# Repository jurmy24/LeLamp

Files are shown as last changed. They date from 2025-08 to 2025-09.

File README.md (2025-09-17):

# LeLamp

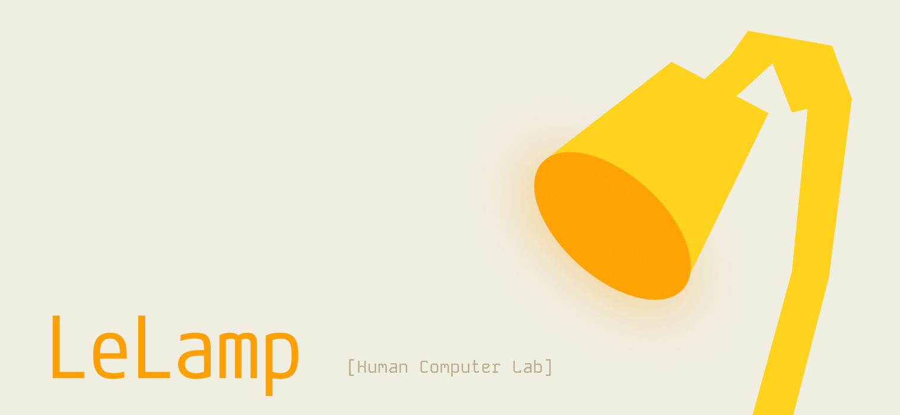
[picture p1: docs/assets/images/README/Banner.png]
LeLamp Banner


An open source robot lamp based on [Apple's Elegnt](https://machinelearning.apple.com/research/elegnt-expressive-functional-movement), made by [Human Computer Lab](https://www.humancomputerlab.com/)

## Overview

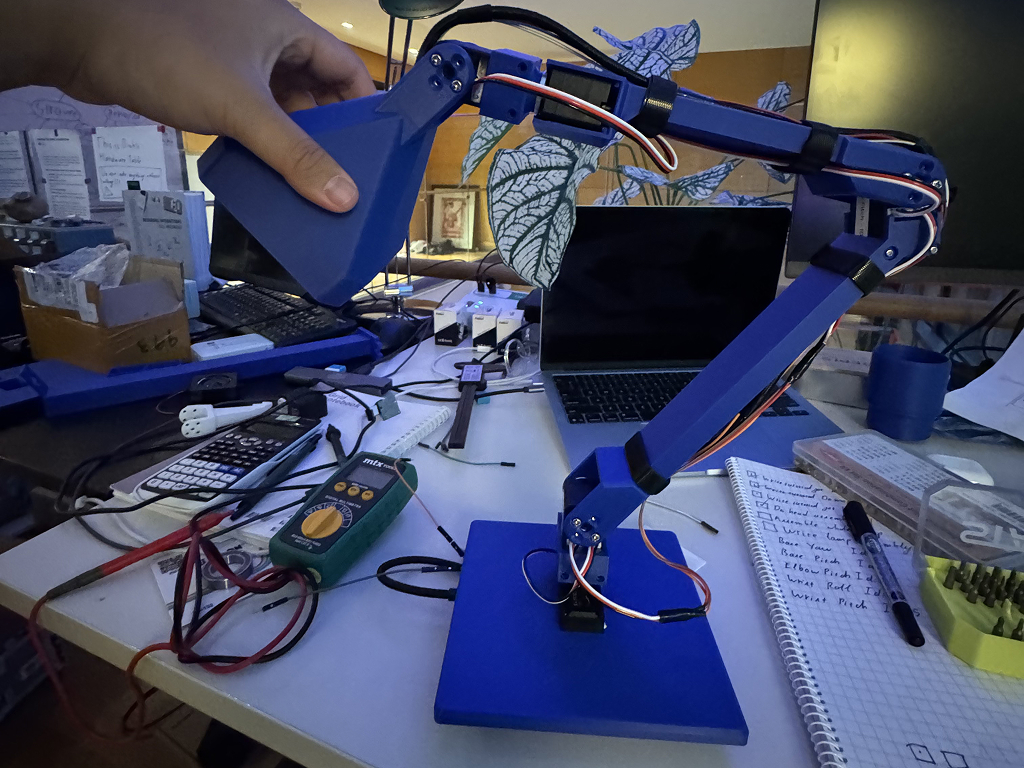
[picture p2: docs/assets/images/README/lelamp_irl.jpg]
LeLamp in real life


**Build specs:** ~$130 cost | 8-12 hours | Intermediate skill level

LeLamp is an expressive robot lamp featuring:

- 🎭 **5-axis articulated movement** with servo motors
- 📸 **Computer vision** via Pi Camera
- 🎤 **Audio interaction** with microphone and speaker
- 💡 **LED expressions** with 24 programmable LEDs
- 🎮 **Record & replay** custom movements

## Build Guide

**Start here:** [Prerequisites & Planning](./docs/0.%20Prerequisites.md)

### Complete Build Process

1. [📋 Prerequisites & Planning](./docs/0.%20Prerequisites.md) - Skills, tools, and BOM
2. [🔧 Components & 3D Parts](./docs/1.%20Schematics.md) - Technical specs and electrical layout
3. [⚙️ Servo Setup](./docs/2.%20Servos.md) - Configure servo motors
4. [🎯 Lamp Head Assembly](./docs/3.%20Lamp%20Head.md) - Pi, camera, audio, LEDs
5. [🏗️ Lamp Body Assembly](./docs/4.%20Lamp%20Body.md) - Mechanical assembly
6. [🎮 Lamp Control](./docs/5.%20Lamp%20Control.md) - Recording and playback
7. [🔍 Troubleshooting](./docs/6.%20Troubleshooting.md) - Common issues and solutions

### Quick Reference

- **Bill of Materials**: [Complete component list with suppliers](./docs/0.%20Prerequisites.md#bill-of-materials)
- **3D Print Files**: Available in `/3D/` directory ([OnShape CAD](https://cad.onshape.com/documents/16c9706360b5ad34f9c8db49/w/2edfa54c83253c120fbc9e58/e/a7196194821d9cfe2842a44a))
- **Software Control**: [LeLamp Runtime Repository](https://github.com/humancomputerlab/lelamp_runtime)

## Project Status

⚠️ **Early Development** - This project is actively being developed. We published our progress early to encourage community feedback and iteration.

## Community & Support

### Getting Help

- **Start here**: [Troubleshooting Guide](./docs/6.%20Troubleshooting.md) for common issues
- **Discord**: [Join our community](https://discord.gg/727JXBt8Zt) for real-time help and discussions
- **GitHub Issues**: [Report bugs or ask questions](https://github.com/humancomputerlab/le_lamp/issues)

### Contributing

We welcome contributions:

- 🐛 Bug reports and fixes
- 📖 Documentation improvements
- 🔧 Design enhancements
- 🌍 Regional supplier information
- 📸 Build photos and videos

Please check existing issues before creating new ones.

## Sponsor

Biggest thanks to Jennie and Lily at Seeed Studio for sponsoring the SO-101 Arm Kit for early developments of LeLamp.

Buy an SO-101 Arm Kit today on [SeeedStudio](https://www.seeedstudio.com/SO-ARM101-Low-Cost-AI-Arm-Kit-p-6426.html).

## License

This project is licensed under the GNU General Public License v3.0 - see the [LICENSE](LICENSE) file for details.

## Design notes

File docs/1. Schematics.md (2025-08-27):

# Building your own LeLamp



The schematic above is for the Pi Zero variation of LeLamp. Scroll down for the normal Pi variation.

## Technical Specifications

### Power Requirements

- **Operating voltage**: 5V DC
- **Total power consumption**: <15W (3A peak)
- **Servo power**: 5V @ 2.5A (all 5 servos under load)
- **Pi and peripherals**: 5V @ 0.5A

LeLamp's servos can also be powered with a 7.4V power supply.

### Performance Specifications

- **Servo torque**: 19kg-cm per servo (STS3215)
- **Position accuracy**: ±2° servo resolution
- **Movement speed**: Up to 60°/second per joint
- **Camera resolution**: 1296x972 @ 30fps
- **Audio**: 16kHz sampling, 2-channel input, mono output
- **LED ring**: 24x WS2812B programmable LEDs

### 3D Printing Requirements

- **Material**: PLA+ recommended (PETG acceptable)
- **Layer height**: 0.2mm standard, 0.15mm for critical parts
- **Infill**: 20% minimum, 30% for structural components
- **Print volume**: 200x200x150mm minimum printer bed

## Electrical Components

**Complete Bill of Materials**: See [Prerequisites Documentation](./0.%20Prerequisites.md#bill-of-materials) for detailed component list with supplier links.

LeLamp is divided into two main sections:

- **Lamp Body** – Houses the mechanical actuation and power conversion systems. This includes:

  - High-torque servos for movement
  - A servo driver board for precise positioning
  - A DC-DC buck converter to regulate 7.4V V down to 5 V for low-voltage electronics

  Think of the Lamp Body like the human torso—it contains the “muscles” (servos) and “circulatory system” (power delivery) that keep the whole device moving.

- **Lamp Head** – Contains the computing and expressive modules, including:

  - Raspberry Pi Zero 2W for control and connectivity
  - Camera module for vision
  - WS2812B RGB LED ring for expressive lighting
  - Microphone and speaker system for audio interaction

  The Lamp Head is like a human head—it houses the “brain” (Pi), the “eyes” (camera), the “ears” (microphone), and the “mouth” (speaker and LEDs).

You can build a functional LeLamp without most of the head components—or even without the head entirely—if you prefer to control the servos directly from an external computer.

## 3D Prints

### With Pi Zero

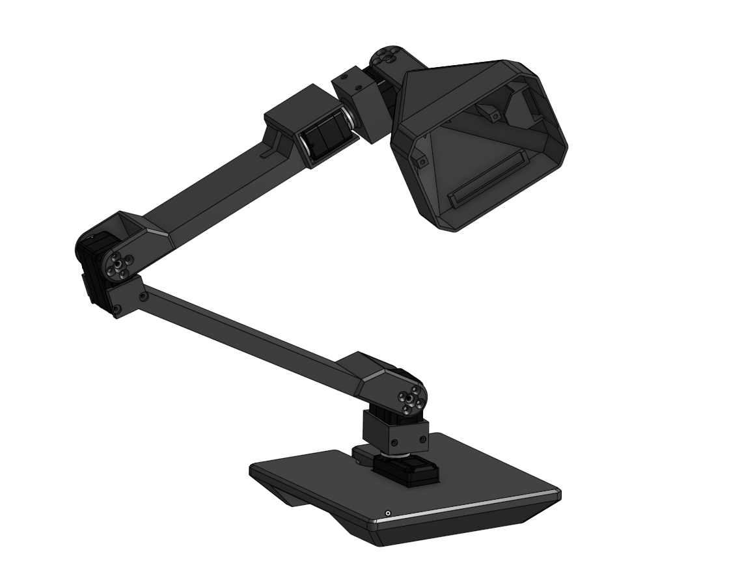
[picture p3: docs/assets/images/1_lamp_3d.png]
3D Lamp


In this variation, LeLamp contains 7 3D printed components:

- **1x Lamp Base**: Contains servo driver, speaker and base yaw servo.
- **1x LampArm (Base to Elbow)**: Contains base pitch and elbow pitch servo.
- **1x LampArm (Elbow to Wrist)**: Contains elbow pitch and wrist roll servo.
- **2x LampArm (Wrist to Head)**: Contains base pitch or wrist pitch servo.
- **1x Lamp Head**: Contains pi zero, led matrix and camera.

You can find the .3mf files for these inside `/3D/`. You can also view it in [OnShape](https://cad.onshape.com/documents/16c9706360b5ad34f9c8db49/w/2edfa54c83253c120fbc9e58/e/a7196194821d9cfe2842a44a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).

### With Normal Pi

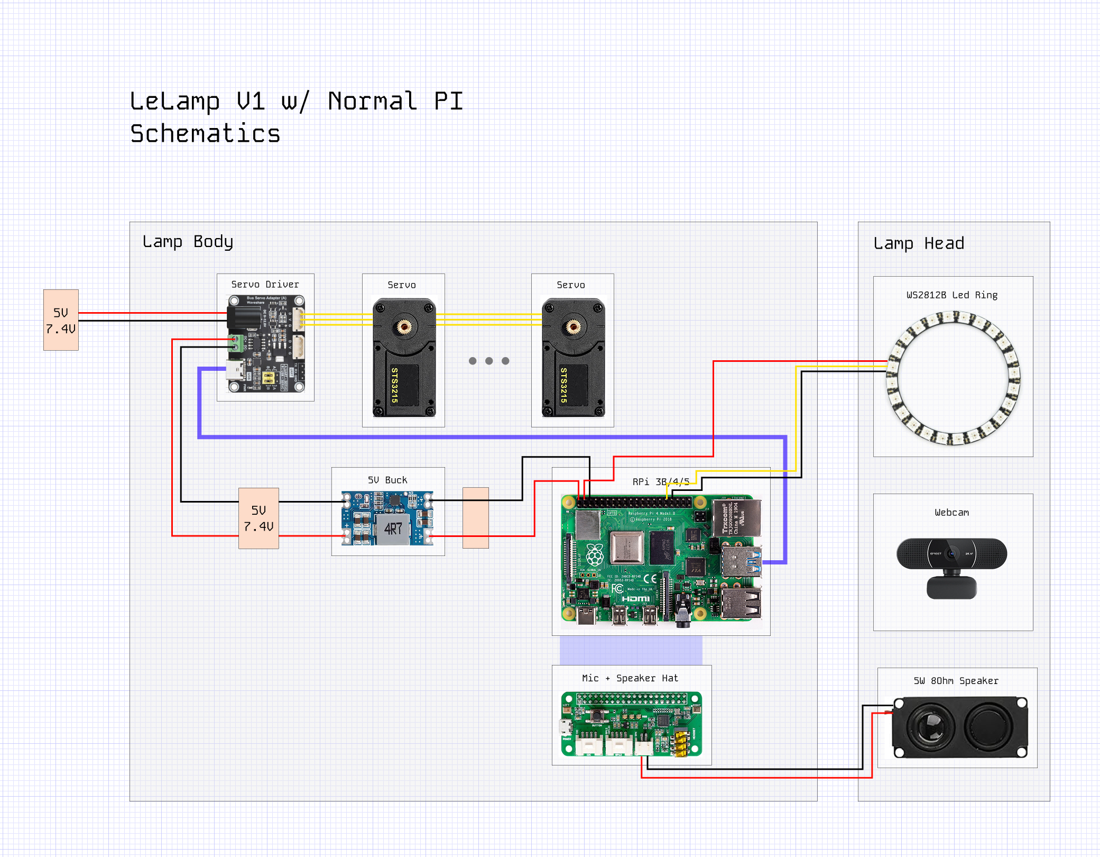
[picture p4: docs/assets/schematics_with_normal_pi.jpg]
Schematic with normal Pi


In this variation, LeLamp contains 7 3D printed components:

- **1x Lamp Base**: Contains servo driver and a normal pi.
- **1x Lamp Base Cover**: Cover lamp base.
- **1x LampArm (Base to Elbow)**: Contains base pitch and elbow pitch servo.
- **1x LampArm (Elbow to Wrist)**: Contains elbow pitch and wrist roll servo.
- **2x LampArm (Wrist to Head)**: Contains base pitch or wrist pitch servo.
- **1x Lamp Head**: Contains led matrix and speaker.

You can find the .3mf files for these inside `/3D/`. The specific files for this version can be found in `/3D/normal_pi_variation/`.

The tutorial will not focus on this version. However, the connection can be referenced from the schematics. The motor orientation and software set up stay the same.

**Previous**: [Prerequisites](./0.%20Prerequisites.md) | **Next**: [Servo Setup](./2.%20Servos.md)

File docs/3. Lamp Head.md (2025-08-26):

# Lamp Head Assembly

**⏱️ Estimated time:** 3-4 hours (including OS setup)  
**🔧 Required tools:** Soldering iron, screwdrivers, heat insert tool  
**📦 Required components:** Pi Zero 2W, ReSpeaker Hat, camera, speaker, LED ring, SD card



LeLamp's head has 4 main functional components:

- **Microphone** - Audio input via ReSpeaker Hat
- **Speaker** - Audio output (4Ω 3W)
- **LED Ring** - 24x WS2812B programmable LEDs for expression
- **Camera** - Pi camera module for vision

All of these components are connected and controlled by a Pi Zero 2W.

## Assembly

Before mounting all components onto the lamp head, it is advised to assemble the electrical components first and test them. You can reference the above image for how this looks like.

### 1. OS

Using [Pi Imager](https://www.raspberrypi.com/software/), flash **Raspberry Pi OS Lite (64-bit)** onto your Raspberry Pi Zero 2W. You can reference how to do this [here](https://www.raspberrypi.com/documentation/computers/getting-started.html). In this tutorial, we used the Debian Bookworm version (released 2025-05-13).

When prompted to configure the settings on your pi, remember to:

- Set the Wifi SSID and password.
- Set the username and password.
- Set the hostname
- Enable SSH

### 2. Runtime

After successfully flashing your pi, SSH into it by running the following command:

```bash
ssh your_username@your_host_name.local
```

Then you need to set up [LeLamp Runtime](https://github.com/humancomputerlab/lelamp_runtime):

```bash
git clone https://github.com/humancomputerlab/lelamp_runtime.git
```

To use LeLamp's runtime, install uv:

```bash
curl -LsSf https://astral.sh/uv/install.sh | sh
```

To setup the runtime:

```bash
cd lelamp_runtime
uv sync --extra hardware
```

This will take a while.

### 3. Setup Mic and Speaker

If you use the ReSpeaker Hat for Raspberry Pi, you can reference their tutorial [here](https://wiki.seeedstudio.com/respeaker_2_mics_pi_hat_raspberry_v2/). For convenience, the tutorial is below:

1. Get Device Tree Source (DTS) for the ReSpeaker 2-Mics Pi HAT (V2.0), compile it and install the device tree overlay.

   ```bash
   curl https://raw.githubusercontent.com/Seeed-Studio/seeed-linux-dtoverlays/refs/heads/master/overlays/rpi/respeaker-2mic-v2_0-overlay.dts -o respeaker-2mic-v2_0-overlay.dts
   dtc -I dts respeaker-2mic-v2_0-overlay.dts -o respeaker-2mic-v2_0-overlay.dtbo
   sudo dtoverlay respeaker-2mic-v2_0-overlay.dtbo
   sudo cp respeaker-2mic-v2_0-overlay.dtbo /boot/firmware/overlays
   ```

2. Edit /boot/firmware/config.txt:

   ```bash
   sudo tee -a /boot/firmware/config.txt >/dev/null <<'EOF'
   dtoverlay=respeaker-2mic-v2_0-overlay
   dtoverlay=i2s-mmap
   EOF
   ```

3. Reboot your device:

   ```bash
   sudo reboot
   ```

4. Check if your device is enabled:

   ```bash
   aplay -l
   ```

   The expected output should be like this:

   ```bash
   card 2: seeed2micvoicec [seeed2micvoicec], device 0: 1f000a4000.i2s-tlv320aic3x-hifi tlv320aic3x-hifi-0 [1f000a4000.i2s-tlv320aic3x-hifi tlv320aic3x-hifi-0]
   Subdevices: 1/1
   Subdevice #0: subdevice #0
   ```

   Afterwards, you can set up the sound level with the following command:

   ```bash
   alsamixer
   ```

5. Install the necessary dependencies for audio:

   ```bash
   sudo apt-get install portaudio19-dev
   ```

### 4. Test functionalities

#### Camera

For camera, run the following command:

```bash
libcamera-hello
```

You should expect an output like this:

```bash
[0:07:48.563548988] [1773]  INFO Camera camera_manager.cpp:326 libcamera v0.5.0+59-d83ff0a4
[0:07:48.749650563] [1777]  WARN RPiSdn sdn.cpp:40 Using legacy SDN tuning - please consider moving SDN inside rpi.denoise
[0:07:48.755845206] [1777]  INFO RPI vc4.cpp:447 Registered camera /base/soc/i2c0mux/i2c@1/ov5647@36 to Unicam device /dev/media2 and ISP device /dev/media0
[0:07:48.756141873] [1777]  INFO RPI pipeline_base.cpp:1121 Using configuration file '/usr/share/libcamera/pipeline/rpi/vc4/rpi_apps.yaml'
Preview window unavailable
Mode selection for 1296:972:12:P
    SGBRG10_CSI2P,640x480/0 - Score: 3296
    SGBRG10_CSI2P,1296x972/0 - Score: 1000
    SGBRG10_CSI2P,1920x1080/0 - Score: 1349.67
    SGBRG10_CSI2P,2592x1944/0 - Score: 1567
Stream configuration adjusted
[0:07:48.781597581] [1773]  INFO Camera camera.cpp:1205 configuring streams: (0) 1296x972-YUV420 (1) 1296x972-SGBRG10_CSI2P
[0:07:48.782340394] [1777]  INFO RPI vc4.cpp:622 Sensor: /base/soc/i2c0mux/i2c@1/ov5647@36 - Selected sensor format: 1296x972-SGBRG10_1X10 - Selected unicam format: 1296x972-pGAA
#0 (0.00 fps) exp 33239.00 ag 8.00 dg 1.00
#1 (30.00 fps) exp 33239.00 ag 8.00 dg 1.00
#2 (30.01 fps) exp 33239.00 ag 8.00 dg 1.00
```

#### RGB

For RGB, run the following command with sudo:

```bash
sudo uv run -m lelamp.test.test_rgb
```

In case you can't find uv as root, run:

```bash
which uv
```

Then replace uv with the output, for example:

```bash
sudo /home/pi/.local/bin/uv run -m lelamp.test.test_rgb
```

If you don't want to do this long path every single time, you can add the path to uv to sudo's secure path:

```bash
sudo visudo
```

Add the following `/home/pi/.local/bin` (Remember to change your username):

```bash
Defaults secure_path="/usr/local/sbin:/usr/local/bin:/usr/sbin:/usr/bin:/sbin:/bin:/home/pi/.local/bin"
```

#### Mic and Speaker

For Mic and Speaker, run the following command:

```bash
uv run -m lelamp.test.test_audio
```

#### Servo

Connect Pi Zero 2W to the servo driver through the USB port, then run the following to find which port the servo is connected to:

```bash
uv run lerobot-find-port
```

Then run the following command to check whether the servos are available:

```bash
uv run -m lelamp.test.test_motors --id your_lamp_name --port port_your_servo_driver_is_connected_to
```

Note: There is an error in LeRobot that makes it impossible to be used on Raspberry Pi. Check the status of this error [here](https://github.com/huggingface/lerobot/issues/1738).

### 5. Assembly

For reference, this will be what the lamp head will look like. Please reference the schematics in **1. Schematics** while doing this step.

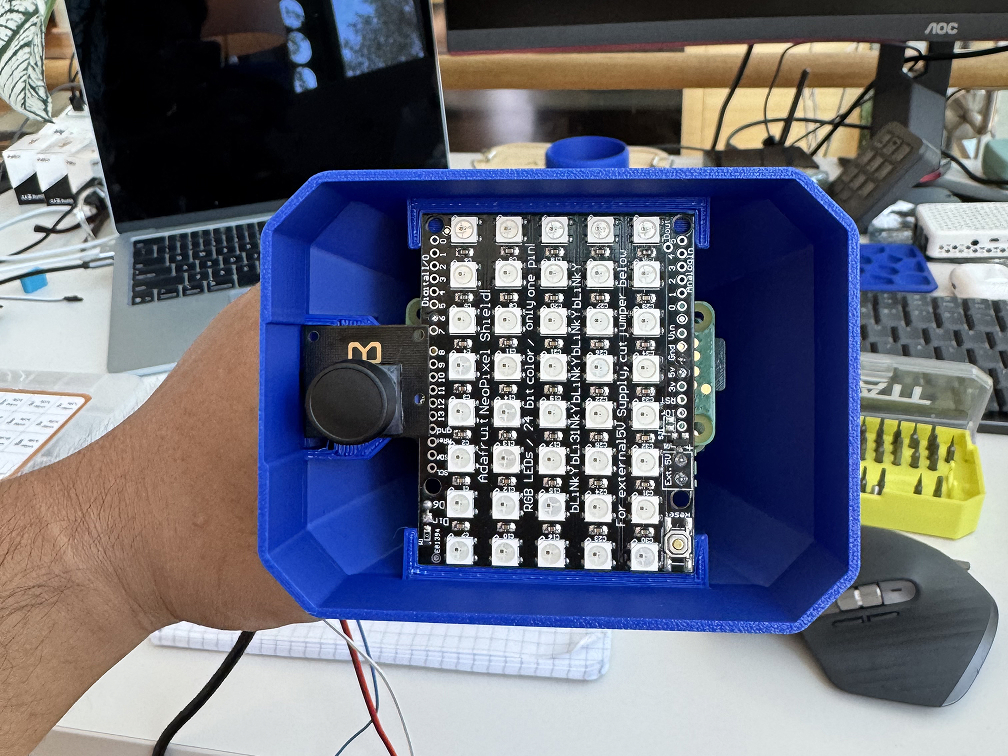
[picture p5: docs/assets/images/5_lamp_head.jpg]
Lamp Head


#### ReSpeaker Hat

Prior to mounting, it is recommended to solder headers on the the ReSpeaker Hat. This will help you connect to components as shown in the schematics.

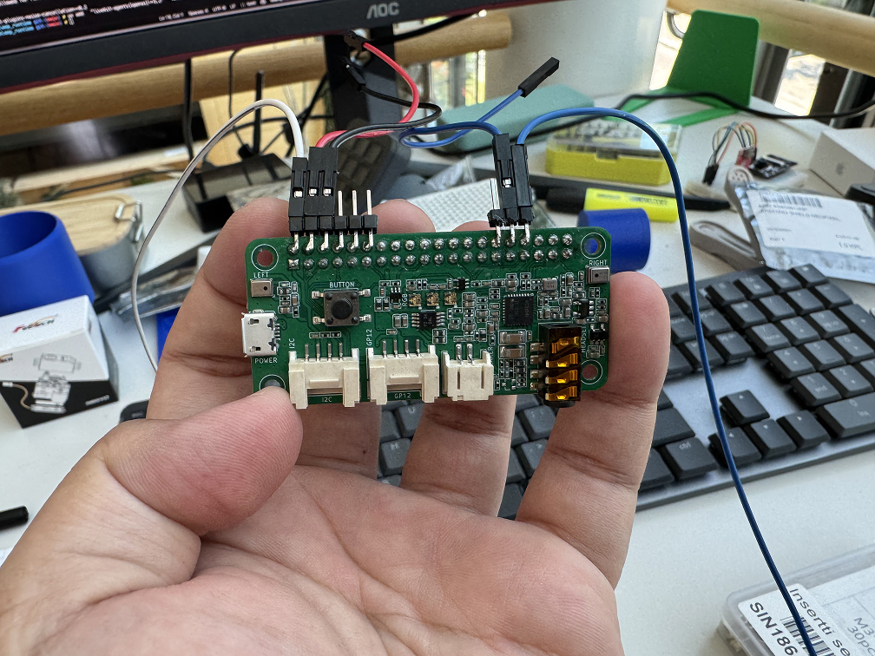
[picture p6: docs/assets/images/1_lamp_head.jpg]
ReSpeaker Hat


Then you should put M2 heat inserts into the mounting pads for the ReSpeaker Hat in the lamp head.

Before screwing the hat in, you should route the wires into the hat first. This includes speaker wire, power wire and rgb wire. It should look like this after mounting.

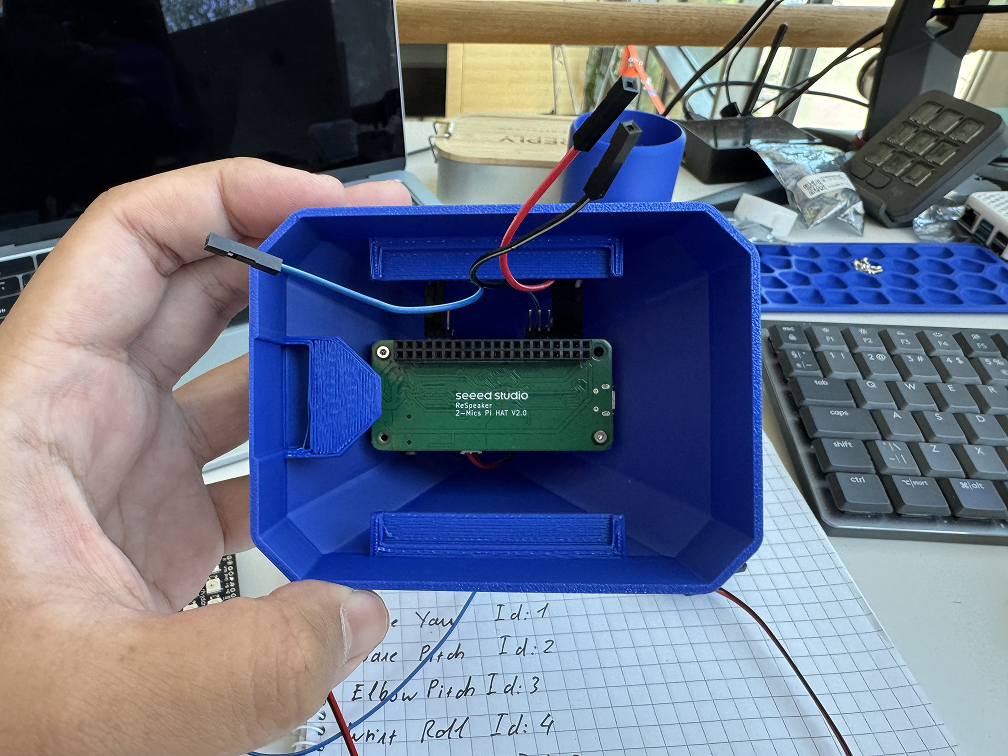
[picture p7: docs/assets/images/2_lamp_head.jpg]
Lamp Head


**At this stage, you should plug in the speaker into the JST2.0 input. Unlike the schematics, you should route this outside the lamp head. This is a temporary design compromise for now, since the speaker is too big.**

#### Raspberry Pi Zero 2W

Slide your Micro USB to Type C wire into the lamp head first, then connect it to the Raspberry Pi Zero 2W.

It should look like this:

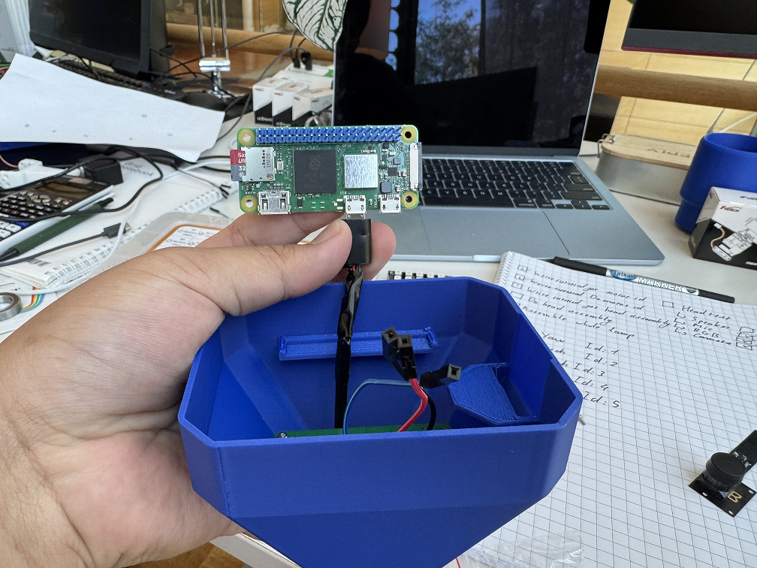
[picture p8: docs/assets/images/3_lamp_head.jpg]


#### RGB Shield And Camera



You should connect the camera by sliding the camera wire into the camera slit first, then connect to the pi.

You can connect the pi to the RGB shield. This should be easy if you have soldered the headers onto the speaker hat before.

## Assembly Completion Checklist

After completing lamp head assembly, verify:

- [ ] Pi Zero 2W boots successfully and connects to WiFi
- [ ] Camera detected and produces clear images (`libcamera-hello`)
- [ ] Audio input/output working (microphone and speaker)
- [ ] LED ring lights up and cycles through colors
- [ ] All connections secure and properly routed
- [ ] LeLamp runtime installed and dependencies working
- [ ] All component tests pass successfully

## What You Should Have

At this stage, you should have:

- **Functional head assembly** with all electronics working
- **Working Pi setup** with SSH access and runtime installed
- **Tested components** - camera, audio, LEDs all operational
- **Proper cable management** with wires routed through head structure

---

**Previous**: [Servo Setup](./2.%20Servos.md) | **Next**: [Lamp Body](./4.%20Lamp%20Body.md)

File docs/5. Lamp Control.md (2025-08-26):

# Lamp Control

**⏱️ Estimated time:** 30 minutes  
**🔧 Required tools:** Computer with LeLamp runtime  
**📦 Required:** Fully assembled LeLamp with working head and body

For complete lamp control documentation, refer to the [**LeLamp Runtime's GitHub**](https://github.com/humancomputerlab/lelamp_runtime).

If you have run tests for LeLamp Head earlier, you should be familiar with the runtime.

## Calibration

Before recording and replaying movements on the lamp, you need to calibrate:

```bash
uv run -m lelamp.calibrate --id lelamp --port /dev/tty.usbmodem5A680114681
```

The calibration script will run calibration twice, once for the lamp as a follower and once for the lamp as the leader.

**Note: Do not rotate the lamp base and lamp head fully while calibrating. This means the 2 yaw servos. In zero position, rotate them 90 degrees clockwise and counter clockwise.**

## Record and replay movements

To record movement, run the following command in runtime:

```bash
uv run -m lelamp.record --id lelamp --port /dev/tty.usbmodem5A680114681 --name rotation
```

To replay movement, run the following command in runtime:

```bash
uv run -m lelamp.replay --id lelamp --port /dev/tty.usbmodem5A680114681 --name rotation
```

To list all recorded movements, run the following command in runtime:

```bash
uv run -m lelamp.list_recordings --id lelamp
```

## Final System Testing

After completing your LeLamp build, perform these final tests:

### Full System Integration Test

```bash
# Test all servo movements
uv run -m lelamp.test.test_motors --id lelamp --port /dev/ttyUSB0

# Test head components
sudo uv run -m lelamp.test.test_rgb     # LED ring
uv run -m lelamp.test.test_audio        # Audio I/O
libcamera-hello --timeout 2000         # Camera
```

### Record Your First Movement

1. **Position LeLamp** in a safe working area with full range of motion
2. **Record a simple movement** to test the system
3. **Replay the movement** to verify accuracy
4. **Save successful recordings** for future use

## Congratulations! 🎉

You have successfully built your LeLamp! Your robot lamp should now be capable of:

- ✅ Expressive movement through 5 degrees of freedom
- ✅ Visual interaction via camera
- ✅ Audio input/output for voice interaction
- ✅ Programmable LED expressions
- ✅ Recording and replaying custom movements

## Next Steps

- **Explore the runtime**: Check out advanced features in the [LeLamp Runtime repository](https://github.com/humancomputerlab/lelamp_runtime)
- **Join the community**: Share your build on [Discord](https://discord.gg/4hmNW3Ep)
- **Contribute back**: Help improve documentation or share build photos
- **Report issues**: Use [GitHub Issues](https://github.com/humancomputerlab/le_lamp/issues) for bugs or suggestions

---

**Previous**: [Lamp Body](./4.%20Lamp%20Body.md) | **Troubleshooting**: [Common Issues](./6.%20Troubleshooting.md)

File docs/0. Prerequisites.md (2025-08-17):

# Prerequisites for Building LeLamp

Before starting your LeLamp build, ensure you have the necessary skills, tools, and time to complete this project successfully.

## Skill Level Requirements

**Intermediate to Advanced** - This project requires:
- **Electronics experience**: Soldering, basic circuit understanding, component identification
- **3D printing knowledge**: Printer operation, material selection, post-processing
- **Software comfort**: Command line usage, SSH, basic Linux administration
- **Mechanical assembly**: Precision work with small components, heat inserts, servo mounting

**Estimated build time**: 8-12 hours over 2-3 days

## Required Tools

### Electronics Tools
- Soldering iron (temperature controlled, 15-25W)
- Solder (60/40 rosin core, 0.6-0.8mm)
- Wire strippers
- Small screwdrivers (Phillips #0, #1, flathead 2-3mm)
- Multimeter for continuity testing
- Anti-static wrist strap (recommended)

### Mechanical Tools  
- Heat insert soldering iron tip OR dedicated heat insert tool
- M2 and M3 Allen keys/hex drivers
- Small pliers (needle nose)
- Wire cutters/flush cutters
- Digital calipers (for verification)

### 3D Printing Requirements
- **Printer bed size**: Minimum 200x200x150mm
- **Materials**: PLA+ recommended (PETG acceptable)
- **Layer height**: 0.2mm standard, 0.15mm for critical parts
- **Infill**: 20% minimum, 30% for structural components
- **Supports**: Required for some parts (see individual STL notes)

## Safety Warnings

⚠️ **ELECTRICAL SAFETY**
- Always disconnect power when making connections
- Use proper ESD precautions when handling Pi and servo driver
- Main power supply is 5V - verify correct voltage before connection
- Double-check polarity before powering on

⚠️ **MECHANICAL SAFETY**
- Heat inserts reach 200°C+ - use appropriate tools
- Servo horns under tension can snap - wear eye protection
- Small parts present choking hazard

## Bill of Materials

### Lamp Body Components
| Component | Quantity | Unit Price | Total | Supplier Link |
|---|---|---|---|---|
| Feetech ST3215 Motor | 5 | $12.00 | $60.00 | [Alibaba](https://www.alibaba.com/product-detail/STS3215-7-4V-19Kg-TTL-Serial_1600114878646.html) |
| Servo Driver | 1 | $4.99 | $4.99 | [Alibaba](https://www.alibaba.com/pla/Serial-Bus-Servo-Driver-Board-Integrates_1600997533603.html) |
| Fixed Output 5V Buck Converter | 1 | $0.75 | $0.75 | [Alibaba](https://www.alibaba.com/product-detail/DC-DC-Buck-3A-Step-down_62035392561.html) |

### Lamp Head Components
| Component | Quantity | Unit Price | Total | Supplier Link |
|---|---|---|---|---|
| Pi Zero 2W | 1 | $15.85 | $15.85 | [Alibaba](https://www.alibaba.com/product-detail/Raspberry-Pi-Zero-2-Development-Board_1600886165825.html) |
| ReSpeaker Hat | 1 | $4.34 | $4.34 | [Alibaba](https://www.alibaba.com/product-detail/Ai-Voice-Applications-Shield-ReSpeaker-2_1601210422054.html) |
| Camera | 1 | $5.00 | $5.00 | [Alibaba](https://www.alibaba.com/product-detail/Aismartlink-Raspberry-Pi-Zero-2W-camera_1601380916187.html) |
| Speaker | 1 | $1.00 | $1.00 | [Alibaba](https://www.alibaba.com/product-detail/100-45mm-8ohm-4watt-High-Sound_1600873138077.html) |
| 24 LEDs WS2812B LED Ring | 1 | $6.20 | $6.20 | [Alibaba](https://www.alibaba.com/product-detail/WS2812B-Module-Strip-24-Bits-24_1600371300450.html) |

### Power & Miscellaneous
| Component | Quantity | Unit Price | Total | Supplier Link |
|---|---|---|---|---|
| 5V 2A DC Power Supply | 1 | $2.00 | $2.00 | [Alibaba](https://www.alibaba.com/product-detail/US-EU-Plug-5V-9V-12V_1600555086691.html) |
| 3D Prints | 1 set | $30.00 | $30.00 | Local printing service |
| Type C to MicroUSB Cable | 1 | $0.50 | $0.50 | [Alibaba](https://www.alibaba.com/product-detail/180-Degree-U-Shape-USB-Type_62447998101.html) |
| 16mm M3 Screws | 4 | - | - | Local hardware store |
| 4mm M2 Screws | 4 | - | - | Local hardware store |
| M2 Heat Inserts | 4 | - | - | Local hardware store |
| M3 Heat Inserts | 8 | - | - | Local hardware store |

**Total estimated cost: $130.63 USD**

## Required External Resources

Before starting, ensure you have access to:
- **3D Printer** or printing service
- **Computer** for Pi setup and servo configuration  
- **WiFi network** for Pi connectivity
- **LeLamp Runtime Repository**: https://github.com/humancomputerlab/lelamp_runtime

## Time Planning

### Phase 1: Preparation (2-3 hours)
- Download and review all documentation
- Source all components
- 3D print all parts
- Set up software environment

### Phase 2: Electronics Prep (2-3 hours)
- Test all components individually
- Solder headers and connectors
- Set up Raspberry Pi OS
- Configure servo IDs

### Phase 3: Assembly (4-6 hours)
- Install heat inserts
- Mount servos in 3D printed parts
- Route wiring through body
- Assemble head components
- Final integration and testing

## Pre-Build Checklist

- [ ] All components sourced and verified working
- [ ] 3D parts printed and post-processed
- [ ] Tools and workspace prepared
- [ ] Software downloaded and accounts created
- [ ] Safety equipment ready
- [ ] Adequate time allocated (don't rush!)

## Getting Help

If you encounter issues:
- **Discord Community**: https://discord.gg/4hmNW3Ep
- **GitHub Issues**: Report bugs and ask questions
- **Documentation**: Always check troubleshooting section first

---

**Next Step**: [1. Building your own LeLamp](./1.%20Schematics.md)

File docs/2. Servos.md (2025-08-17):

# Servo Setup

**⏱️ Estimated time:** 30-45 minutes  
**🔧 Required tools:** Computer, servo driver, USB cable  
**📦 Required components:** 5x STS3215 servos, servo driver board

The first part of building your LeLamp is setting up your servos.

## 1. Unbox and lay your servos on a table.

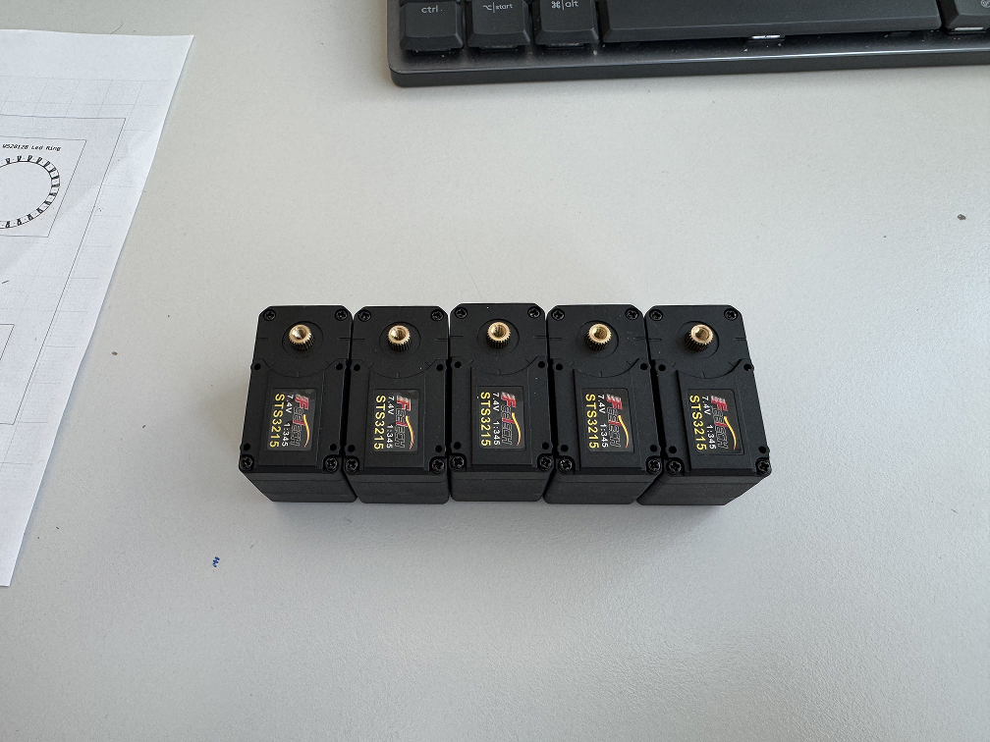
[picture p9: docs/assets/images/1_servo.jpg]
Servos on table


## 2. Label your servos.

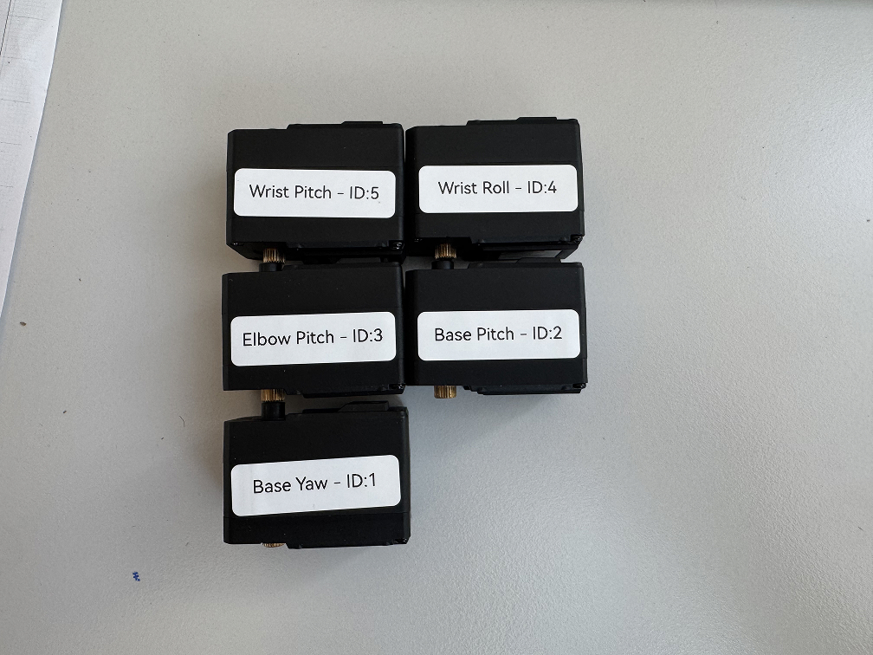
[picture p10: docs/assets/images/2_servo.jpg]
Label your servos.


| Servo Name  | Servo ID |
| --- | --- |
| base_yaw | 1 |
| base_pitch  | 2 |
| elbow_pitch | 3 |
| wrist_roll  | 4 |
| wrist_pitch | 5 |

Based on the table above, you should label your servo accordingly. There's no particular order to this or specific servo you should label with a certain ID.

The end result is having 5 servos, each with a label that tells you which is which.

## 3. Run LeLamp's motor setup script.

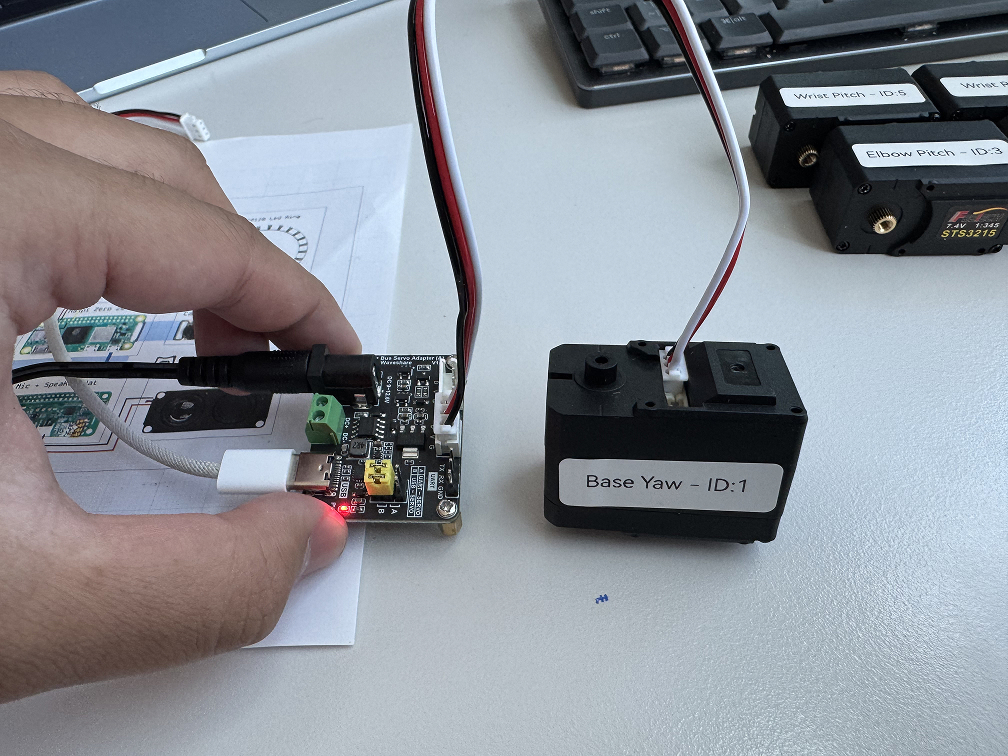
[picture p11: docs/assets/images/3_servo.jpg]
Run LeLamp's motor setup script


After labeling your servo, connect the servo driver to your computer and figure which port it is connected to.

Inside `lelamp_runtime`, you can find port this by running:

```bash
uv run lerobot-find-port
```

For motor setup, inside `lelamp_runtime`, run the following command and connect the servo accordingly:

```bash
uv run -m lelamp.setup_motors --id your_lamp_name --port port_your_servo_driver_is_connected_to
```

Example:

```bash
uv run -m lelamp.setup_motors --id lelamp --port /dev/tty.usbmodem5A680114681
```

Remember the name you set for your lamp, you will use it again in the future.

## Success Criteria

After completing servo setup, you should have:
- [ ] 5 servos labeled with their intended positions
- [ ] All servos responding correctly to commands
- [ ] Servo IDs properly configured (1-5)
- [ ] Motor setup script completed successfully

## Troubleshooting

**Common issues:**
- **Servo not detected**: Check USB connection and port
- **Permission errors**: May need `sudo` or add user to dialout group
- **Servo ID conflicts**: Ensure each servo has unique ID

---

**Previous**: [Schematics](./1.%20Schematics.md) | **Next**: [Lamp Head](./3.%20Lamp%20Head.md)

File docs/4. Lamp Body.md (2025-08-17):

# Lamp Body Assembly

**⏱️ Estimated time:** 2-3 hours  
**🔧 Required tools:** Heat insert tool, Allen keys (M2/M3), screwdrivers, wire management tools  
**📦 Required components:** 3D printed parts, 5 servos, heat inserts, screws, buck converter

After assembling your lamp head, the body is next.

## Prerequisites

This assumes you have already:
- ✅ Printed all 3D parts and removed supports
- ✅ Completed servo setup with proper IDs
- ✅ Assembled and tested lamp head
- ✅ Prepared all electrical components

If you haven't done this, reference the [Schematics documentation](./1.%20Schematics.md).

## Assembling

There is no particular order to assemble LeLamp's body. You can start from any part of the body.

To help this process, we divided LeLamp's body into 2 parts:

- **Upper Body**: From elbow to wrist
- **Lower Body**: From base to elbow

### Upper Body



You can reference this image for servo placement. For servo orientation, please refer to the section below.

### Lower Body



You can reference this image for servo placement. For servo orientation, please refer to the section below.

### Servo Orientation



You can reference this image for pitch servo orientation. If you look at LeLamp from a top down view, with wire slit on the base facing right, the pitch servo horns should face outward from you or should face ahead.



You can reference this image for yaw and roll servo orientation. **For these servos, you don't need to attach the support horn (the horn that doesn't have the gears)**.

## Electronics

If you assemble you lamp head according to the guide and the schematic, there should be these coming out of the head:

- A speaker
- A pair of 5V and ground wire for the pi
- A type c wire

You should route these wires along the body of the lamp. It is recommended to use wire organizers here, either tie, wire spirals or wire sleeves.

It should look like this from the side:

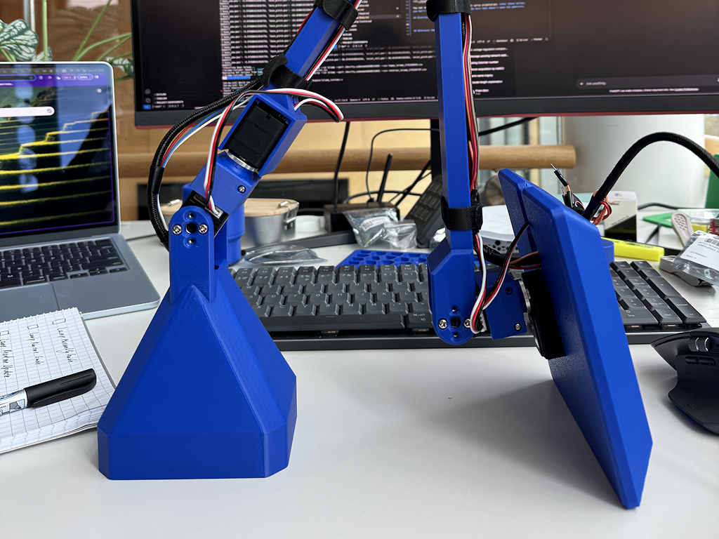
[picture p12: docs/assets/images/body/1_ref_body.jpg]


On the bottom of the base, here is a reference image:

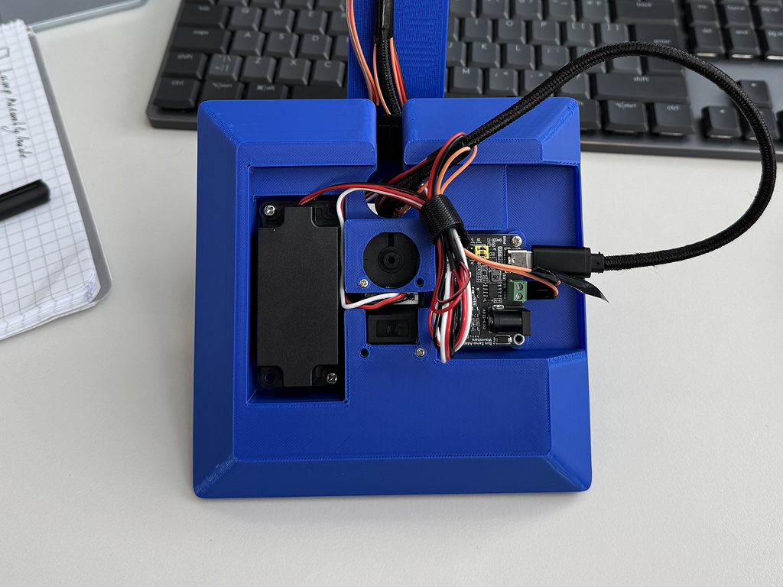
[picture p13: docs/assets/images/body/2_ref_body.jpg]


To screw in the speaker and servo driver, you can use heat inserts, but it is not required to do so. Screws should be able to tap their own threads into the prints.

Route your wires according to the schematic.

## Assembly Completion Checklist

After completing lamp body assembly, verify:
- [ ] All servos properly mounted in 3D printed parts
- [ ] Servo horns correctly oriented (pitch outward, yaw/roll without support horn)
- [ ] All heat inserts installed securely
- [ ] Servo driver and speaker mounted in base
- [ ] Power wiring completed (5V from buck converter)
- [ ] All cables properly routed and organized
- [ ] No mechanical interference between moving parts
- [ ] Joints move smoothly through full range of motion

## What You Should Have

At this stage, you should have:
- **Complete mechanical assembly** with all 5 servos installed
- **Functional power system** with buck converter providing stable 5V
- **Proper cable management** using wire organizers or sleeves
- **Tested movement** - all joints should move without binding

## Safety Notes

⚠️ **Before powering on the complete system:**
- Double-check all power connections for correct polarity
- Ensure no short circuits between power and ground
- Verify servo cables are properly connected
- Test individual components before full integration

---

**Previous**: [Lamp Head](./3.%20Lamp%20Head.md) | **Next**: [Lamp Control](./5.%20Lamp%20Control.md)

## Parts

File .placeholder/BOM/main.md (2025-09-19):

# Main BOM

| Component | Quantity | Unit Cost | Total Cost |
| --- | --- | --- | --- |
| base | 1 | 10 | 10 |

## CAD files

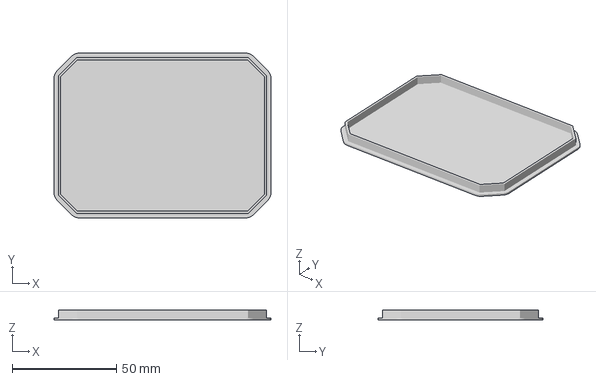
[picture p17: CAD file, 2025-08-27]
3D/Diffuser.3mf
104.0 x 79.0 x 5.00 mm

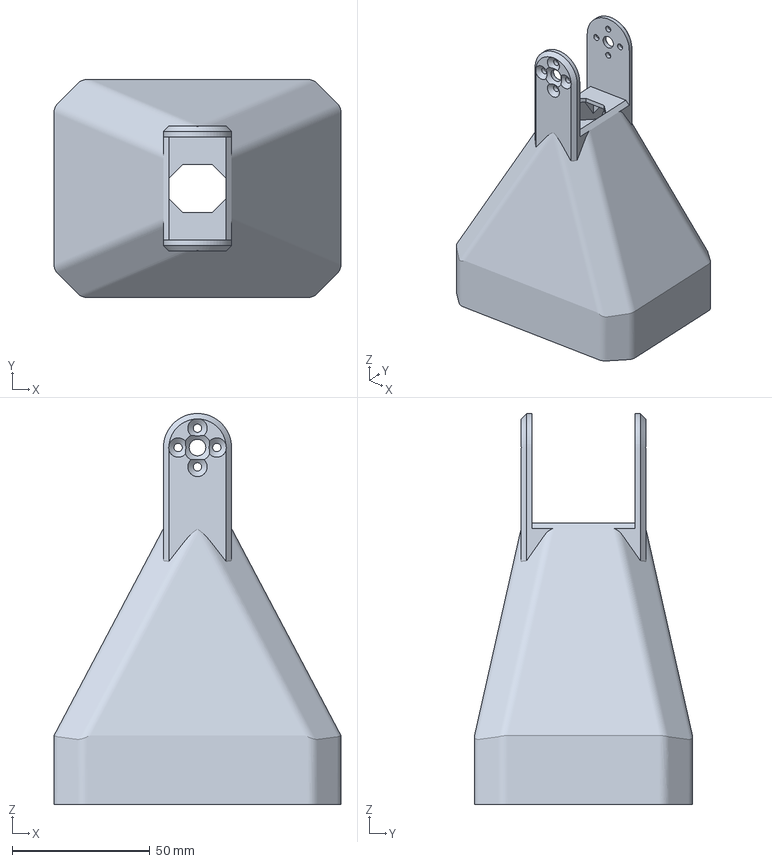
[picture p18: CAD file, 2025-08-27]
3D/normal_pi_variation/Lamp Head.3mf
104.0 x 79.0 x 141.7 mm

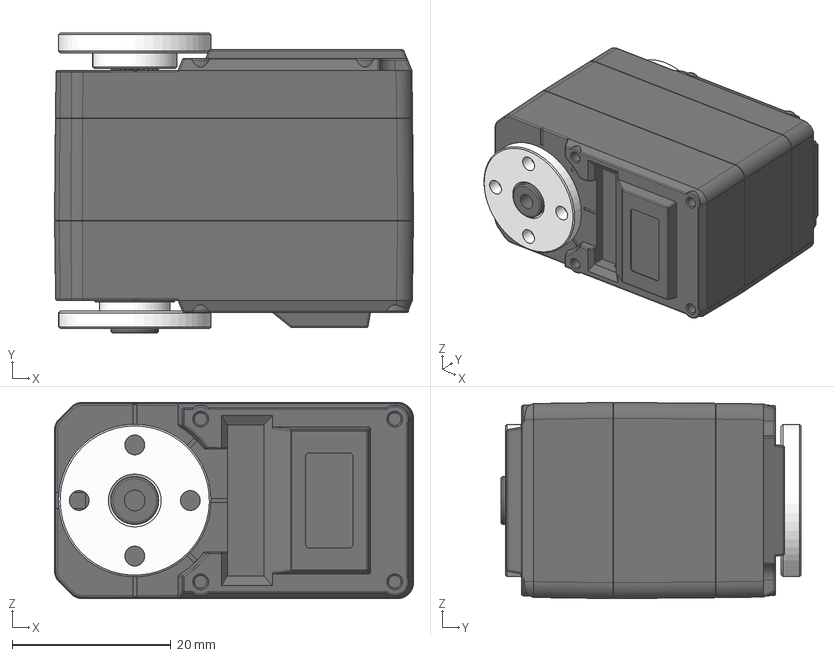
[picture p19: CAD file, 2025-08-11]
docs/assets/step/ST3215.step
45.2 x 37.8 x 24.7 mm
ZK_122
SG-ZIJI_15
XG-ZIJI_16
MOTOR-1723_3
PCB-CHAZUO_92
GE_27
金属舵盘（驱动）
金属舵盘（从动）

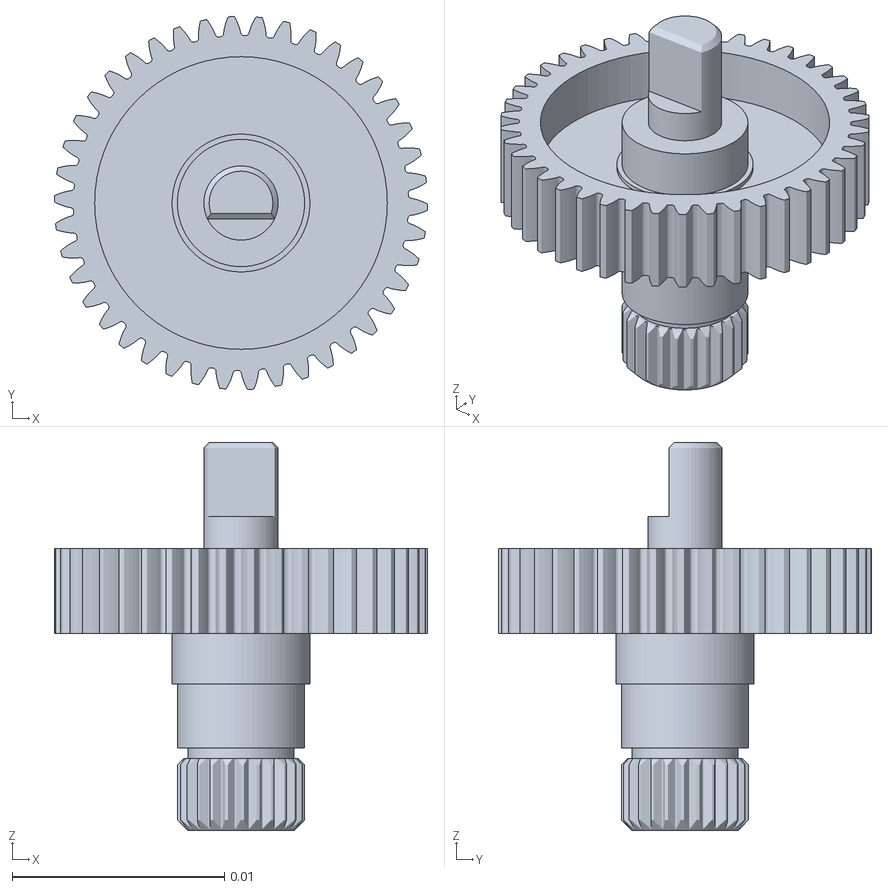
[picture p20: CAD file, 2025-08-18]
simulation/assets/ge_27.stl
0.0176 x 0.0176 x 0.0183

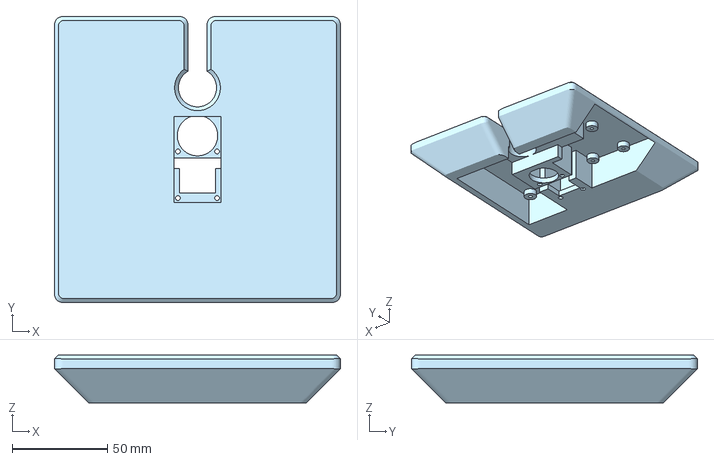
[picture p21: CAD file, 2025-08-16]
3D/Lamp Base (Rectangle).3mf
150.0 x 150.0 x 25.0 mm

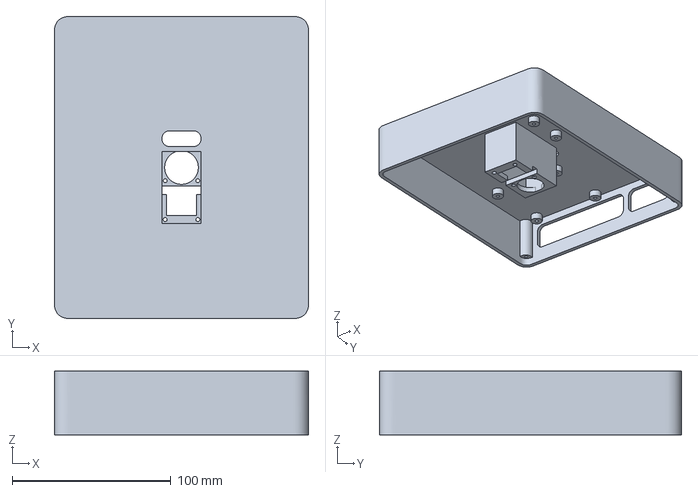
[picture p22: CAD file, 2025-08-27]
3D/normal_pi_variation/Lamp Base.3mf
160.0 x 190.0 x 40.0 mm

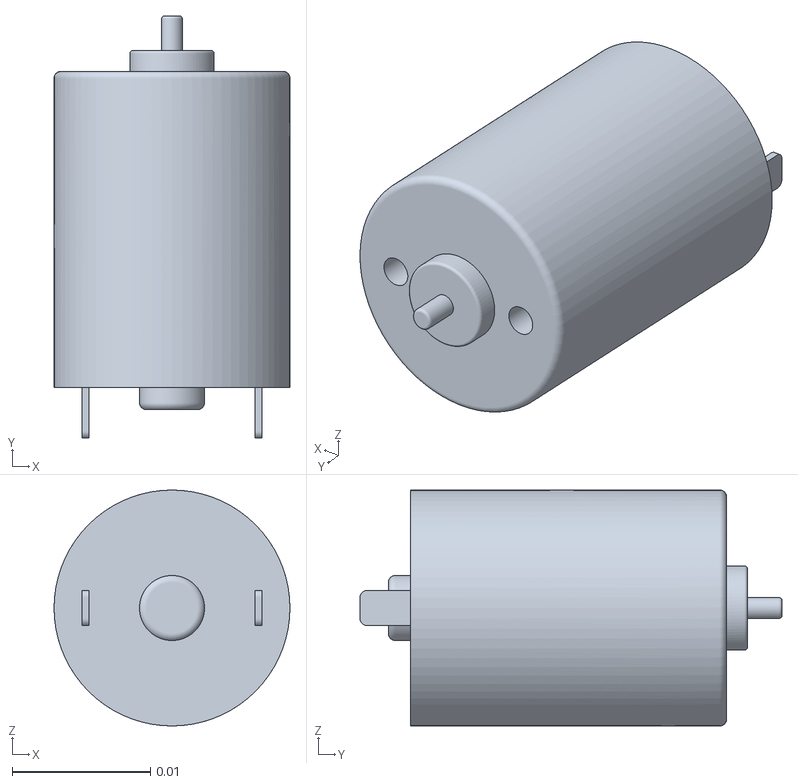
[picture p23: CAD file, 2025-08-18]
simulation/assets/motor_1723_3.stl
0.017 x 0.0305 x 0.017

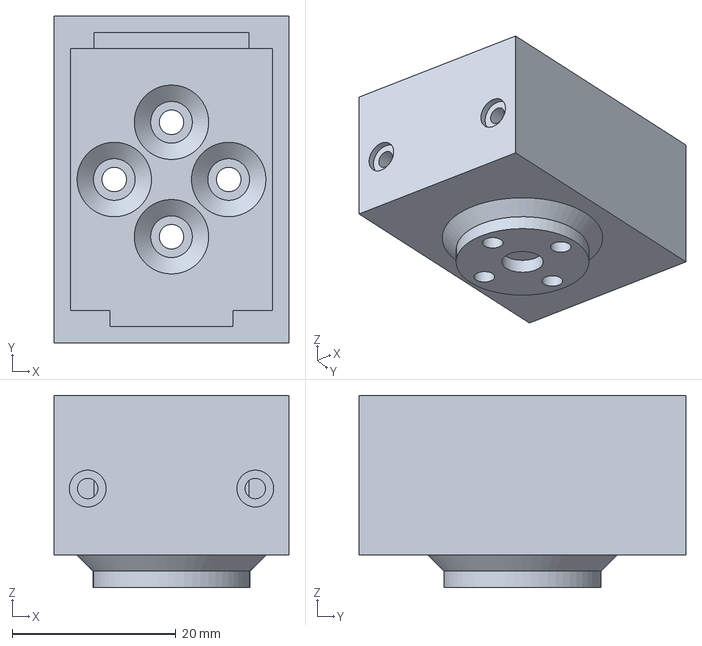
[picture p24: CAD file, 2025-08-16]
3D/LampArm (Wrist-Head).3mf
28.7 x 40.0 x 23.5 mm

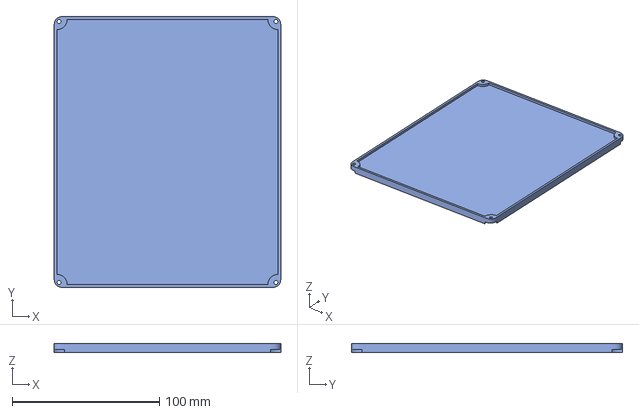
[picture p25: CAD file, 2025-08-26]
3D/normal_pi_variation/Lamp Base Cover.3mf
153.8 x 183.8 x 6.00 mm

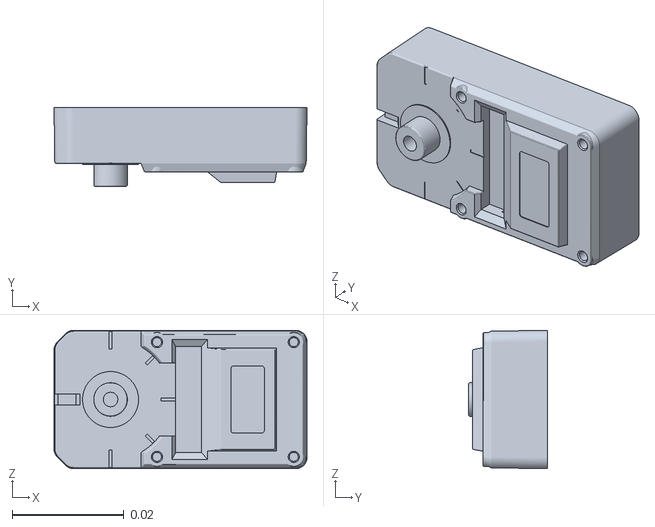
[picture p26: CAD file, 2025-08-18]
simulation/assets/xg_ziji_16.stl
0.0452 x 0.0141 x 0.0247

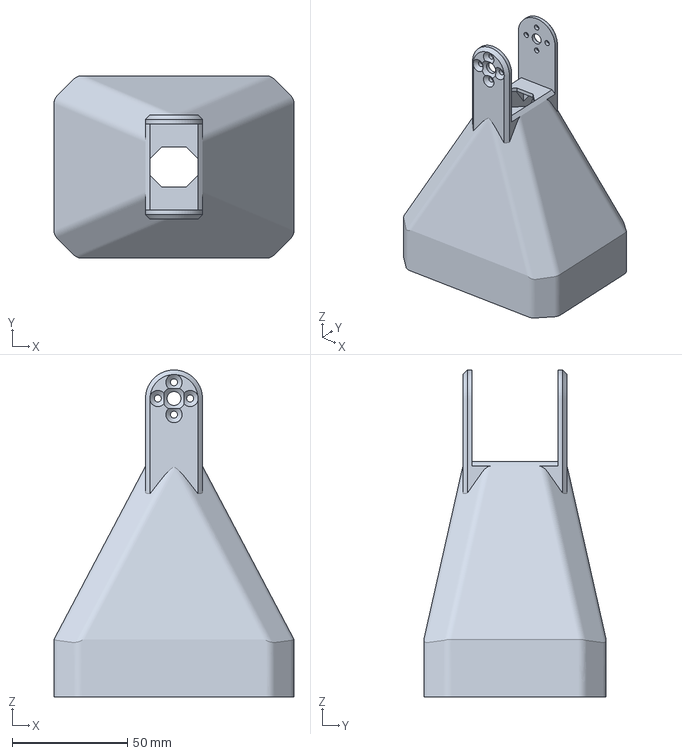
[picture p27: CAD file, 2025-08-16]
3D/LampHead - LampHead.3mf
104.0 x 79.0 x 141.7 mm

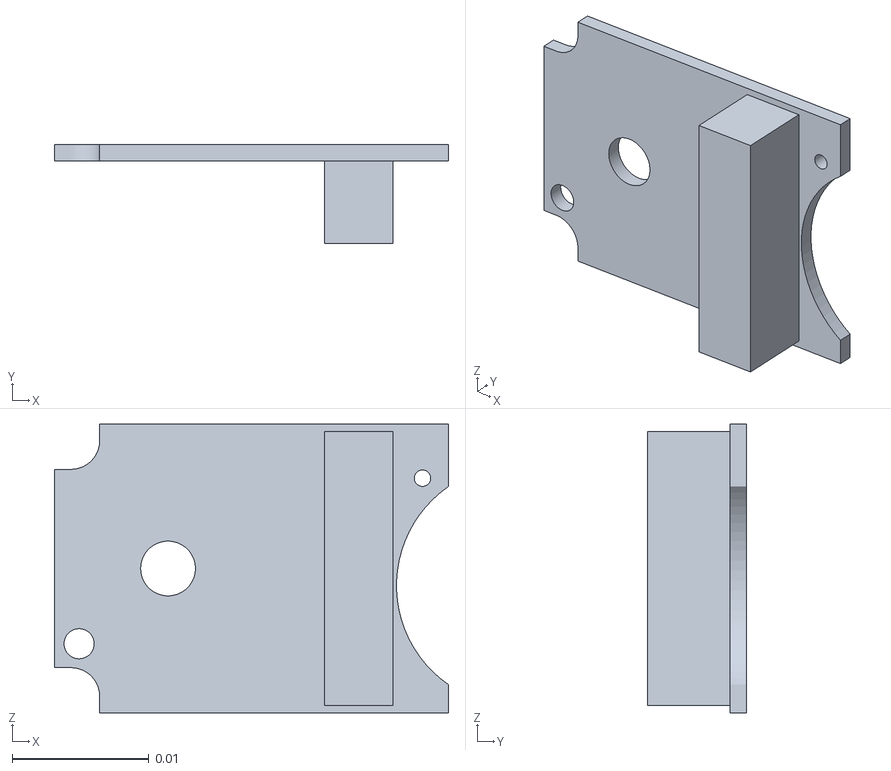
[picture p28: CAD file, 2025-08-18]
simulation/assets/pcb_chazuo_92.stl
0.0288 x 0.0072 x 0.0211

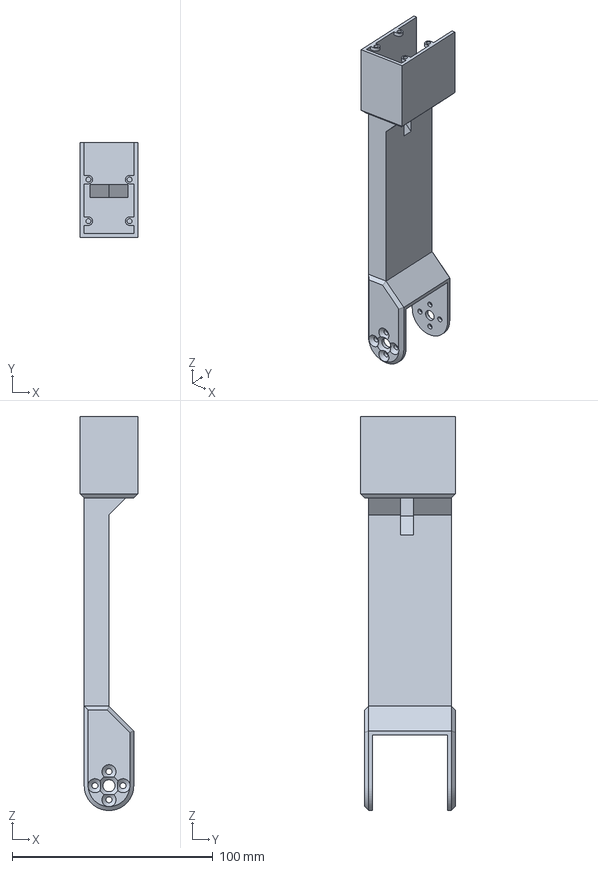
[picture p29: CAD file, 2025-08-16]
3D/LampArm (Elbow-Wrist).3mf
28.7 x 47.2 x 196.3 mm

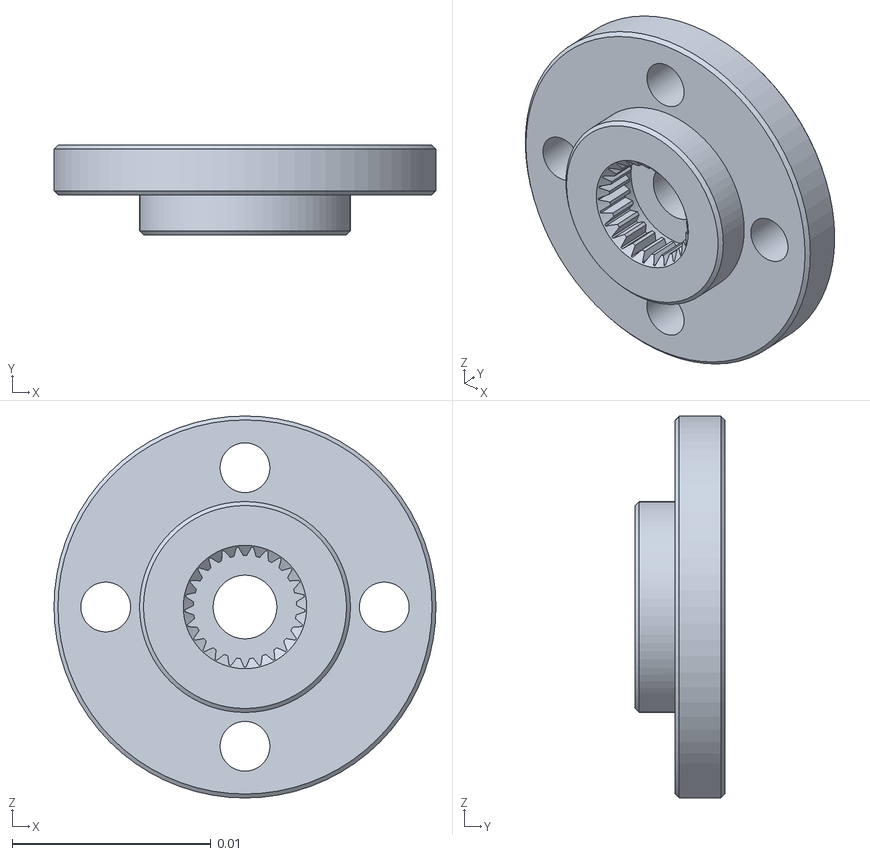
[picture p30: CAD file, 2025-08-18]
simulation/assets/金属舵盘_驱动__v2.stl
0.0192 x 0.0045 x 0.0192

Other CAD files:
3D/LampArm (Base-Elbow).3mf
simulation/assets/lamparm__wrist_head.stl
simulation/assets/lamparm__base_elbow.stl
simulation/assets/金属舵盘_从动__v2.stl
simulation/assets/angle_joint.stl
simulation/assets/arm_length_10cm.stl
simulation/assets/arm_length_15cm.stl
simulation/assets/b3b_eh.stl
simulation/assets/base.stl
simulation/assets/bts2_m2_6x8.stl
simulation/assets/dc15_a01_case_b_dummy.stl
simulation/assets/dc15_a01_case_f_dummy.stl
simulation/assets/dc15_a01_case_m_dummy.stl
simulation/assets/dc15_a01_horn_dummy.stl
simulation/assets/dc15_a01_horn_idle2_dummy.stl
simulation/assets/dc15_a01_idle_cap_dummy.stl
simulation/assets/dc15_a01_led_cap2_dummy.stl
simulation/assets/lamp_base.stl
simulation/assets/lamp_head.stl
simulation/assets/lamparm__elbow_wrist.stl
simulation/assets/lamphead.stl
simulation/assets/sg_ziji_15.stl
simulation/assets/square_joint.stl
simulation/assets/zk_122.stl

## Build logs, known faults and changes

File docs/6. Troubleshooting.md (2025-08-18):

# LeLamp Troubleshooting Guide

This guide covers common issues encountered during LeLamp assembly and operation, with step-by-step solutions.

## Hardware Issues

### Servo Problems

**Problem**: Servo not responding or moving erratically
- **Check power supply**: Ensure 5V supply provides adequate current for all servos
- **Verify connections**: Check servo driver to servo cable connections
- **Test individual servos**: Disconnect other servos and test one at a time
- **Check servo IDs**: Run `uv run lerobot-find-port` to verify servo driver connection
- **Reset servo settings**: Re-run the motor setup script from scratch

**Problem**: Servo making grinding noises
- **Check for obstructions**: Ensure no 3D print supports or debris block movement
- **Verify servo horn alignment**: Incorrect horn position can cause binding
- **Check mechanical stress**: Ensure arms are properly aligned and not over-torqued

**Problem**: Intermittent servo movement
- **Check power supply voltage**: Use multimeter to verify stable 5V under load
- **Inspect cable connections**: Look for loose or damaged servo cables
- **Test at lower speeds**: Rapid movements may cause voltage drops

### Electronics Issues

**Problem**: Pi Zero 2W not booting
- **Check SD card**: Ensure proper OS image and card not corrupted
- **Verify power supply**: Pi needs stable 5V, check buck converter output
- **Check connections**: Ensure micro USB power cable is properly connected
- **Try different SD card**: Use a known-good card with fresh OS image

**Problem**: Camera not detected
- **Check ribbon cable**: Ensure camera cable is properly seated in Pi connector
- **Enable camera**: Run `sudo raspi-config` and enable camera interface
- **Test with libcamera**: Run `libcamera-hello` to verify camera functionality
- **Check for damage**: Inspect ribbon cable for tears or bent pins

**Problem**: Audio not working (ReSpeaker Hat)
- **Verify HAT connection**: Ensure ReSpeaker is properly seated on Pi headers
- **Check device tree overlay**: Verify overlay installation with `aplay -l`
- **Reinstall audio drivers**: Follow ReSpeaker setup steps again
- **Test with alsamixer**: Adjust audio levels and check device recognition

**Problem**: LED ring not lighting
- **Check power connections**: Verify 5V power to LED ring
- **Test data line**: Ensure GPIO pin connection is secure
- **Run LED test**: Use `sudo uv run -m lelamp.test.test_rgb`
- **Check for damaged LEDs**: Individual LEDs can fail and break the chain

### 3D Printing Issues

**Problem**: Parts don't fit together properly
- **Check print scale**: Ensure parts printed at 100% scale
- **Verify layer height**: Use 0.2mm or finer for critical tolerance parts
- **Post-process parts**: Remove support material and sand contact surfaces
- **Check printer calibration**: Ensure X/Y/Z steps are properly calibrated

**Problem**: Heat inserts won't stay in place
- **Use proper temperature**: Heat insert tool should reach 200-250°C
- **Proper technique**: Insert slowly and steadily, don't rush
- **Check hole size**: Verify 3D model holes are correct diameter
- **Consider thread locker**: Use low-strength thread locker if inserts are loose

## Software Issues

### Pi Setup Problems

**Problem**: Cannot SSH into Pi
- **Check network connection**: Verify Pi is connected to WiFi
- **Verify SSH enabled**: Ensure SSH was enabled during OS setup
- **Check hostname**: Try IP address instead of hostname.local
- **Firewall issues**: Temporarily disable computer firewall for testing

**Problem**: Runtime installation fails
- **Check internet connection**: Ensure Pi has stable internet access
- **Update system**: Run `sudo apt update && sudo apt upgrade` first
- **Install uv manually**: Follow official uv installation instructions
- **Check disk space**: Ensure sufficient space on SD card (16GB+ recommended)

**Problem**: Permission errors during testing
- **Use sudo for hardware tests**: RGB and some sensor tests require root access
- **Check user groups**: Add pi user to gpio, i2c, spi groups
- **Verify device permissions**: Check /dev/ device file permissions

### Known Issues and Workarounds

**LeRobot Compatibility Issue** (docs/3. Lamp Head.md:185)
- **Status**: [Active issue #1738](https://github.com/huggingface/lerobot/issues/1738)
- **Impact**: Cannot use LeRobot directly on Raspberry Pi
- **Workaround**: Use LeLamp runtime which includes compatibility fixes
- **Alternative**: Set up servo control from external computer via USB

## Diagnostic Commands

### System Health Checks
```bash
# Check system resources
free -h
df -h
vcgencmd get_throttled

# Check hardware interfaces
lsusb
i2cdetect -y 1
gpio readall

# Test camera
libcamera-hello --timeout 2000

# Check audio devices
aplay -l
arecord -l
```

### Servo Diagnostics
```bash
# Find servo driver port
uv run lerobot-find-port

# Test servo connectivity
uv run -m lelamp.test.test_motors --id lelamp --port /dev/ttyUSB0

# Manual servo control (replace port)
uv run -m lelamp.control --id lelamp --port /dev/ttyUSB0
```

### Network and Software
```bash
# Check network connectivity
ping google.com
ip addr show

# Verify Python environment
which uv
uv --version
python3 --version

# Check service status
systemctl status ssh
systemctl status networking
```

## Getting Additional Help

### Before Asking for Help
1. **Check this troubleshooting guide** thoroughly
2. **Search existing GitHub issues** for similar problems
3. **Collect diagnostic information** using commands above
4. **Take clear photos** of your setup if hardware-related

### Where to Get Help
- **GitHub Issues**: https://github.com/humancomputerlab/le_lamp/issues
- **Discord Community**: https://discord.gg/4hmNW3Ep
- **LeLamp Runtime Issues**: https://github.com/humancomputerlab/lelamp_runtime/issues

### What Information to Include
- **Problem description**: Clear, specific description of the issue
- **Steps to reproduce**: Exact sequence that leads to the problem
- **Error messages**: Complete error text, not screenshots of text
- **System information**: Pi model, OS version, hardware configuration
- **Photos**: Clear images of your setup for hardware issues

## Component Testing Order

When diagnosing issues, test components in this order:

1. **Power supply**: Verify voltage and current capacity
2. **Individual servos**: Test each servo separately
3. **Servo driver**: Verify communication and control
4. **Pi connectivity**: Ensure SSH and basic operation
5. **Individual sensors**: Camera, microphone, speakers separately
6. **Integrated systems**: Full lamp operation

This systematic approach helps isolate problems and avoid cascading failures.

---

**Previous**: [5. Lamp Control](./5.%20Lamp%20Control.md)

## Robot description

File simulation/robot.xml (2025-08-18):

<?xml version="1.0" ?>
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
<mujoco model="simulation">
  <compiler angle="radian" meshdir="assets" autolimits="true"/>
  <default>
    <default class="simulation">
      <joint frictionloss="0.1" armature="0.005"/>
      <position kp="50" dampratio="1"/>
      <default class="visual">
        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
      </default>
      <default class="collision">
        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
      </default>
    </default>
  </default>
  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
  <sensor>
    <accelerometer name="accel_sensor" site="imu_site"/>
    <gyro name="gyro_sensor" site="imu_site"/>
  </sensor>
  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
  <default>
    <default class="sts3215">
      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
      <joint damping="0.60" frictionloss="0.052" armature="0.028"/>
      <position kp="17.8" kv="0.0" forcerange="-3.35 3.35"/>
    </default>
    <default class="backlash">
      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
      <joint damping="0.01" frictionloss="0" armature="0.01" limited="true" range="-0.008726646259971648 0.008726646259971648"/>
    </default>
  </default>
  <worldbody>
    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
    <body name="lamparm__base_elbow" pos="0 0 0" quat="1 0 0 0" childclass="simulation">
      <freejoint name="lamparm__base_elbow_freejoint"/>
      <inertial pos="-0.0229181 0.00297443 0.185358" mass="0.134549" fullinertia="0.000472889 0.000498762 8.10272e-05 1.27811e-05 0.000145734 -5.93489e-05"/>
      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
      <body name="scs215_v5" pos="0.0154636 0.00756357 0.08031" quat="0.585897 -0.395884 0.585897 0.395884">
        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
        <joint axis="0 0 1" name="2" type="hinge" range="-1.931840663764446 1.209751989825347" class="sts3215"/>
        <inertial pos="0.0180556 0.000605864 -0.0197123" mass="0.0852562" fullinertia="8.7923e-06 1.82503e-05 1.4956e-05 -3.86833e-07 9.72694e-07 6.73016e-08"/>
        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
      </body>
    </body>
    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
    <body name="lamparm__wrist_head" pos="0 0 0" quat="1 0 0 0" childclass="simulation">
      <freejoint name="lamparm__wrist_head_freejoint"/>
      <inertial pos="0.00827959 -0.0103008 0.0499315" mass="0.0101242" fullinertia="2.18249e-06 1.57724e-06 2.87377e-06 -2.90349e-07 -5.3858e-09 -1.33928e-08"/>
      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
      <body name="scs215_v5_2" pos="0.0083 -0.01025 0.0392" quat="0.190013 5.21098e-16 2.06035e-17 0.981782">
        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
        <joint axis="0 0 1" name="1" type="hinge" range="-5.09473967719376 1.188445629985826" class="sts3215"/>
        <inertial pos="0.0165258 0.00729871 -0.0197123" mass="0.0852562" fullinertia="1.03767e-05 1.66659e-05 1.4956e-05 -3.55311e-06 8.77345e-07 4.25356e-07"/>
        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
      </body>
    </body>
    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
    <body name="lamparm__elbow_wrist" pos="0 0 0" quat="1 0 0 0" childclass="simulation">
      <freejoint name="lamparm__elbow_wrist_freejoint"/>
      <inertial pos="-0.144104 0.0515418 0.248908" mass="0.107291" fullinertia="0.000121928 0.000236114 0.000188338 4.83306e-05 -0.000107412 4.00557e-05"/>
      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
      <body name="scs215_v5_3" pos="-0.0718619 0.0433005 0.303327" quat="0.200162 -0.438741 -0.554533 -0.678185">
        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
        <joint axis="0 0 1" name="3" type="hinge" range="-2.609605990859412 0.5319866627303811" class="sts3215"/>
        <inertial pos="-0.0158677 0.00863651 -0.0197123" mass="0.0852562" fullinertia="1.08876e-05 1.61549e-05 1.4956e-05 3.94674e-06 -8.72407e-07 4.35395e-07"/>
        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
      </body>
    </body>
    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
    <body name="lamparm__wrist_head_2" pos="0 0 0" quat="1 0 0 0" childclass="simulation">
      <freejoint name="lamparm__wrist_head_2_freejoint"/>
      <inertial pos="-0.222648 0.0973951 0.190378" mass="0.0101242" fullinertia="2.50556e-06 1.63778e-06 2.49016e-06 -4.30575e-07 2.47192e-07 -1.10648e-07"/>
      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
      <body name="scs215_v5_4" pos="-0.214533 0.0940727 0.196565" quat="0.451637 -0.16736 -0.871922 -0.0881301">
        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
        <joint axis="0 0 1" name="4" type="hinge" range="-3.14466826187895 3.1385170453006364" class="sts3215"/>
        <inertial pos="0.000661393 -0.0180537 -0.0197123" mass="0.0852562" fullinertia="1.82478e-05 8.79477e-06 1.4956e-05 4.15915e-07 7.02929e-08 -9.72482e-07"/>
        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
      </body>
    </body>
    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
    <body name="scs215_v5_5" pos="0 0 0" quat="1 0 0 0" childclass="simulation">
      <freejoint name="scs215_v5_5_freejoint"/>
      <inertial pos="-0.232145 0.101705 0.18377" mass="0.0852562" fullinertia="1.21537e-05 1.51057e-05 1.47392e-05 3.77963e-07 -4.48721e-06 1.13263e-06"/>
      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
      <body name="lamphead" pos="-0.25283 0.0887792 0.172816" quat="0.622164 -0.701394 -0.0823972 -0.337887">
        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
        <joint axis="0 0 1" name="5" type="hinge" range="-2.1841514133949023 0.9574412401948911" class="sts3215"/>
        <inertial pos="-0.0646673 -0.0451799 0.0186249" mass="0.0833107" fullinertia="0.000138437 0.000147289 0.000170035 -1.20464e-05 -4.1948e-10 1.29183e-10"/>
        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
      </body>
    </body>
    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
    <body name="lamp_base" pos="0 0 0" quat="1 0 0 0" childclass="simulation">
      <freejoint name="lamp_base_freejoint"/>
      <inertial pos="-0.00977932 -0.0138894 0.0149535" mass="0.363855" fullinertia="0.000661257 0.000822089 0.00144905 4.24141e-05 -8.60647e-06 -9.71008e-08"/>
      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
    </body>
  </worldbody>
  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
  <actuator>
    <position class="sts3215" name="2" joint="2" inheritrange="1"/>
    <position class="sts3215" name="1" joint="1" inheritrange="1"/>
    <position class="sts3215" name="3" joint="3" inheritrange="1"/>
    <position class="sts3215" name="4" joint="4" inheritrange="1"/>
    <position class="sts3215" name="5" joint="5" inheritrange="1"/>
  </actuator>
  <equality/>
</mujoco>

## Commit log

2025-08-05 Add mujoco models
    [angle_joint.stl, arm_length_10cm.stl, arm_length_15cm.stl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]
2025-08-06 Gym env
    [robot.xml]
2025-08-07 Update Mujoco models
    [dc15_a01_horn_dummy.stl, robot.urdf, robot.xml]
2025-08-08 Added gymnasium for rl
    [.monitor.csv, angle_joint.stl, arm_length_10cm.stl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]
2025-08-08 Update training notebooks for RL
    [monitor.csv]
2025-08-11 Add schematics and docs
2025-08-11 Add drawings
    [ST3215.step]
2025-08-13 new tutorials
    [angle_joint.stl, arm_length_10cm.stl, arm_length_15cm.stl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]
2025-08-15 Add more tutorials
    [CameraHolder.3mf, Lamp Base (Rectangle).3mf, LampArm (Base-Elbow).3mf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]
2025-08-16 Finalize documentation
    [.monitor.csv, Lamp Base (Rectangle).3mf, LampArm (Base-Elbow).3mf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]
2025-08-18 Update Simulation
    [ge_27.stl, lamp_base.stl, lamparm__base_elbow.stl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]
2025-08-26 Add new Lamp version for normal size pi
    [Base-Arm Mount.3mf, Lamp Base Cover.3mf, Lamp Base.3mf]
2025-08-27 Update new lamp design for normal pi variation
    [Base-Arm Mount.3mf, Diffuser.3mf, Lamp Base.3mf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]
2025-09-19 Update BOM tables - Main BOM
2025-09-19 Update BOM tables - BOM Index
